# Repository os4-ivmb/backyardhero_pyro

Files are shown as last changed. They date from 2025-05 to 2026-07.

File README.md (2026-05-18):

# Backyard Hero

An open-source 2.4 GHz wireless fireworks firing system. Custom hardware, a
web-based show builder, sub-10 ms cross-receiver sync — schematics, firmware,
and the host app all public.

<div align="center">
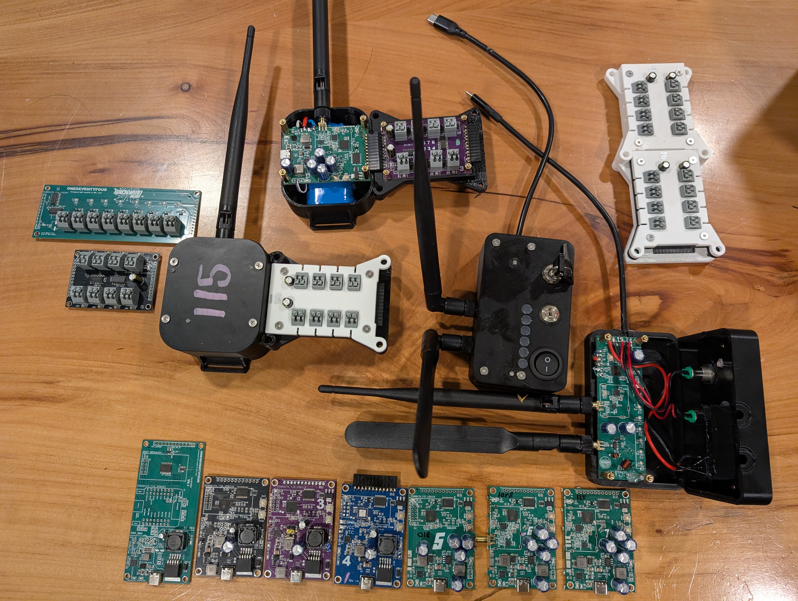
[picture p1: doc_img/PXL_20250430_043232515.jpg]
Backyard Hero — receivers, dongle, and cue modules
  
</div>

## Docs live elsewhere

This README is intentionally short. There are two places to look:

- **[backyard-hero.com](https://backyard-hero.com)** — overview, hardware
  walkthrough, what the system can do, how it gets run, photos. Start here if
  you've just landed on the repo.
- **[Project wiki](https://github.com/os4-ivmb/backyardhero_pyro/wiki)** —
  getting started by OS, system architecture, wire protocol, firmware
  deep-dives, REST API reference, and everything else you need to actually
  build, flash, and run the system.

A few jumping-off points in the wiki:

- [Getting Started](https://github.com/os4-ivmb/backyardhero_pyro/wiki/Getting-Started)
  ([macOS](https://github.com/os4-ivmb/backyardhero_pyro/wiki/Getting-Started-macOS)
  · [Linux](https://github.com/os4-ivmb/backyardhero_pyro/wiki/Getting-Started-Linux)
  · [Windows](https://github.com/os4-ivmb/backyardhero_pyro/wiki/Getting-Started-Windows))
- [System Architecture](https://github.com/os4-ivmb/backyardhero_pyro/wiki/System-Architecture)
  and [Glossary & Terms](https://github.com/os4-ivmb/backyardhero_pyro/wiki/Glossary-and-Terms)
- [Connecting the Dongle](https://github.com/os4-ivmb/backyardhero_pyro/wiki/Connecting-the-Dongle)
  · [Flashing a Receiver](https://github.com/os4-ivmb/backyardhero_pyro/wiki/Flashing-a-Receiver)

## Running it locally

Each platform has its own folder under `host/run/`. Pick yours, follow the
README inside.

| Platform | Folder | Quickstart |
| --- | --- | --- |
| **Raspberry Pi** (controller / AP) | [`host/run/pi/`](host/run/pi/README.md) | `sudo host/run/pi/install.sh` |
| **macOS** (dev) | [`host/run/osx/`](host/run/osx/README.md) | `host/run/osx/start.sh` (prod) or `start-dev.sh` (hot reload) |
| **Windows** (dev) | [`host/run/windows/`](host/run/windows/README.md) | `host\run\windows\start.bat` |

Then open `http://localhost:1776` (or `http://backyardhero/` on the Pi's AP).

## Repository layout

- `host/` — Next.js show builder, Python firework daemon, WebSocket server,
  serial bridge.
- `devices/` — receiver, dongle, and cue-module firmware, plus PCB design
  notes and enclosure CAD.

## License

[DBAD](https://dbad-license.org/) — don't be a dick.

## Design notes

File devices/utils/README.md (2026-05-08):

# devices/utils

Host-side helpers for building and provisioning OS4 firmware.

## Receiver flow (FW v14+)

Pre-v14 each receiver needed its own custom build because `NODE_ID` and
`RECEIVER_IDENT` were `#define`s in the sketch. v14 moves identity into
the chip's NVS partition (`byh_rx` namespace) so one binary serves the
whole fleet, and identity is written over USB serial after flashing.

The flash workflow is built around **NVS preservation**: routine firmware
updates write only the app partition, so once a receiver has been
provisioned, its `NODE_ID` and ident persist forever -- through every
firmware update, until you explicitly wipe them.

### One-time setup (host)

```bash
brew install arduino-cli
```

That's it. `arduino-cli` reuses your existing `~/Library/Arduino15`
install for the ESP32 core, so you don't have to reinstall anything if
you've ever built via the Arduino IDE on this machine.

`flash_receiver.py` self-bootstraps a Python venv at `devices/utils/.venv`
on first run and installs `pyserial` + `esptool` into it -- you don't
need to deal with Homebrew Python's PEP 668 protection or manage
dependencies by hand. To rebuild the venv from scratch (e.g. after a
Python upgrade), just `rm -rf devices/utils/.venv` and run the script
again.

### Build

```bash
devices/utils/build_receiver.sh
```

- Reads `#define FW_VERSION` from `devices/os4_receiver/os4_receiver.ino`.
- Compiles for `esp32:esp32:lolin_s2_mini` via `arduino-cli`.
- Writes the same four files the Arduino IDE produces, into
  `devices/os4_receiver/bin/`:
  - `os4_receiver_v<N>.bin` -- app partition (~340 KB). Flashed at
    `0x10000` for routine updates.
  - `os4_receiver_v<N>.bootloader.bin` -- chip bootloader. Flashed at
    `0x1000` during `--full`.
  - `os4_receiver_v<N>.partitions.bin` -- partition table. Flashed at
    `0x8000` during `--full`.
  - `os4_receiver_v<N>.boot_app0.bin` -- OTA next-app pointer (static
    arduino-esp32 file). Flashed at `0xe000` during `--full`.
- Updates `bin/latest.*` symlinks.

To produce new artifacts alongside the old ones, bump `FW_VERSION` in
the sketch (and add notes to the version-history block at the top of the
file). Re-running at the same `FW_VERSION` overwrites the existing bins.

### Flash + provision

Three modes, picked via flags. The script always picks the
highest-versioned matching bin (override with `--bin <path>`).

#### Routine update (already-provisioned receiver)

```bash
devices/utils/flash_receiver.py
```

App-only flash at `0x10000` -- exactly what the Arduino IDE does for an
upload to a board that's already been flashed. Preserves `NODE_ID` and
ident. After the flash, the script reads the boot banner over serial
and confirms the receiver came back up with its previous identity.

#### First-time flash (virgin chip / recovery)

```bash
devices/utils/flash_receiver.py --full
```

Writes bootloader + partitions + boot_app0 + app in one esptool
invocation -- exactly the four-file layout the Arduino IDE writes for a
fresh upload. **Also preserves NVS**, because the default ESP32-S2
partition table puts NVS at `0x9000-0xdfff`, in the gap between the
partition table (`0x8000-0x8fff`) and `boot_app0` (`0xe000-0xffff`),
and we don't write anything in that gap.

After the flash, prompts for receiver number 1-254 and sends `SETID
<node_id> RX<node_id>` over serial to provision the new identity. (For
a brand-new chip, NVS is empty after this flash and the receiver boots
into UNPROVISIONED mode -- which is exactly what `SETID` resolves.)

Use this for:
- A brand new ESP32-S2 chip that has never been flashed.
- Recovery after a corrupt partition table or other surgery.
- Whenever the partition layout itself changes (e.g. you added or
  resized a partition in `partitions.csv`).

#### Re-provision (change the receiver number on an existing unit)

```bash
devices/utils/flash_receiver.py --set-id
```

App-only flash followed by an interactive `SETID`. Use this to renumber
a receiver in the field (or to provision one that ended up
unprovisioned for any reason) without wiping the rest of NVS.

Equivalent to `flash_receiver.py` followed by manually sending a
`SETID` command -- but in one step.

#### Skip the prompts

```bash
devices/utils/flash_receiver.py --full --port /dev/tty.usbmodem01 --node 146
# (ident defaults to RX146; pass --ident to override)
```

`--node` and `--ident` work with both `--full` and `--set-id`.

### Re-provisioning a unit in the field (no flash)

You don't need to re-flash to change `NODE_ID`. Use the dedicated
helper:

```bash
devices/utils/set_node_id.py                            # prompts for everything
devices/utils/set_node_id.py --node 146                 # ident defaults to RX146
devices/utils/set_node_id.py --get                      # just read current ID
devices/utils/set_node_id.py --wipe                     # back to UNPROVISIONED
```

This is the right tool when the chip already has working firmware and
you just need to renumber it. (`flash_receiver.py --set-id` does the
same thing but also re-flashes the app first.)

Under the hood, both scripts open the receiver's USB serial port at
115200 8N1 and send one of these commands -- which the firmware accepts
at any time:

```
GETID
SETID <node_id> <ident>
WIPEID
```

`SETID` and `WIPEID` reboot the chip after writing.

### Behavior summary

| Mode | Files written | NVS  | Auto SETID | When to use |
| --- | --- | ---- | --- | --- |
| (default)  | app @ 0x10000 | kept | no | routine updates |
| `--full` | bootloader + partitions + boot_app0 + app | kept | yes (prompt) | virgin chip / recovery |
| `--set-id` | app @ 0x10000 | kept | yes (prompt)  | renumber a unit |

### Troubleshooting

**`Could not configure port: (6, 'Device not configured')` or
`Connecting...` hangs at the "connecting" step.**

The lolin_s2_mini runs its user firmware over USB-CDC, and the chip's
ability to respond to esptool's auto-reset signals (DTR/RTS over USB)
depends on what the user app is doing at the moment esptool tries to
talk. When auto-reset fails, the script automatically prompts you to
put the chip into ROM bootloader mode by hand:

1. Press and HOLD the BOOT button on the receiver.
2. While still holding BOOT, press and release RESET.
3. Release BOOT.
4. Press Enter at the prompt.

The script then retries with `--before no_reset` and the flash
proceeds. Once the new firmware boots, auto-reset usually works again
for the next flash.

If the retry also fails:
- Unplug and replug the receiver to recycle the USB endpoint.
- Make sure nothing else is holding the serial port (Arduino IDE Serial
  Monitor, `screen`, another terminal, etc.).
- Try a different USB cable -- some "charging" cables don't carry data.

**`esptool not found` or `pyserial not installed`.**

`flash_receiver.py` self-bootstraps a venv at `devices/utils/.venv` on
first run. If something is wrong with the venv, just delete it and
re-run:

    rm -rf devices/utils/.venv

### Future: OTA

The same app-only artifact (`os4_receiver_v<N>.bin`) is what an OTA
flow will push -- both paths land at offset `0x10000` and preserve NVS,
so a unit can be provisioned once over USB and updated indefinitely
over the air.

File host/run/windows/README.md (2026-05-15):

# host/run/windows -- Windows development

Local development on Windows with Docker Desktop and the ESP32-S2
dongle plugged into USB (typically `COM3` / `COM4`).

## Files in this folder

| File | What it does |
| --- | --- |
| `start.bat` | Prod launcher: pulls `os4ivmb/backyardhero:latest`, starts the bridge + Docker stack. |
| `docker-compose.yml` | Prod compose. Maps host port 1776 (not 80 -- avoids collisions with IIS or other Windows services). |
| `build_and_push_docker.bat` | Multi-arch build + push to Docker Hub (mirror of the osx script). |

There's no `start-dev.bat` yet -- if you need hot-reload dev on
Windows, run WSL2 and use the `osx/` flow from there (Linux paths
work the same as the mac scripts and Docker Desktop integrates with
WSL2).

## Prereqs

- Windows 10/11 with Docker Desktop installed and running.
- Python 3 in `PATH`. Install from <https://python.org>; check
  "Add Python to PATH" during install.
- The dongle plugged into USB. It'll show up as `COM<N>` in Device
  Manager.

## Run it

```cmd
cd host\run\windows
start.bat
```

The script opens a separate window for the TCP-to-serial bridge
(close it to stop the bridge) and runs `docker compose up` in the
main window (Ctrl-C to stop the stack).

Open <http://localhost:1776/> in your browser.

## Why no port 80?

Same reason as macOS: Windows dev boxes often have IIS, other
services, or just-in-case dev servers on port 80. Binding it from
Docker risks "port already in use" errors. The Pi compose binds 80
because the Pi is dedicated hardware; on a Windows dev box you're
just hitting localhost so :1776 is fine.

## Cutting a new image for the Pi

```cmd
cd host\run\windows
build_and_push_docker.bat
build_and_push_docker.bat --no-push
```

You'll need `docker login` first. The script pulls `host_version`
from `host\config\systemcfg.json` via PowerShell.

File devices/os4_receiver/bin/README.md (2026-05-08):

# Receiver firmware binaries

Build artifacts produced by `devices/utils/build_receiver.sh` land here.

Per `FW_VERSION` we keep four files, exactly the ones the Arduino IDE
flashes when it pushes a build:

- `os4_receiver_v<N>.bin` -- app partition (~340 KB). Flashed at
  **0x10000**. This is the only file `flash_receiver.py` writes for a
  routine update.
- `os4_receiver_v<N>.bootloader.bin` -- chip bootloader. Flashed at
  **0x1000** during a `--full` first-time flash.
- `os4_receiver_v<N>.partitions.bin` -- partition table. Flashed at
  **0x8000** during a `--full` first-time flash.
- `os4_receiver_v<N>.boot_app0.bin` -- OTA "next-app" pointer (static
  arduino-esp32 file, copied here so the flash helper doesn't have to
  dig through `~/Library/Arduino15`). Flashed at **0xe000** during a
  `--full` first-time flash.

NVS lives at `0x9000-0xdfff` in the default ESP32-S2 partition table --
in the gap between the partition table and `boot_app0`. `flash_receiver.py`
never writes anything in that gap, so **NODE_ID and RECEIVER_IDENT
survive both routine flashes and `--full` flashes**.

Symlinks:

- `latest.bin` -> newest `os4_receiver_v<N>.bin`
- `latest.bootloader.bin` -> newest `os4_receiver_v<N>.bootloader.bin`
- `latest.partitions.bin` -> newest `os4_receiver_v<N>.partitions.bin`
- `latest.boot_app0.bin` -> newest `os4_receiver_v<N>.boot_app0.bin`

`FW_VERSION` is read from `#define FW_VERSION` in `os4_receiver.ino` at
build time. Re-building at the same `FW_VERSION` overwrites all four
files; bump `FW_VERSION` in the sketch to keep multiple versions
side-by-side.

`.bin` files are gitignored -- these are local build artifacts. Tag
releases in git if you want to pin a particular firmware version.

See `devices/utils/README.md` for the flash workflow.

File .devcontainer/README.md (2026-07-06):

# .devcontainer — Backyard Hero host

A [Dev Container](https://containers.dev) that runs the full host stack
(Next.js show builder + Python firework daemon + WebSocket server) with
hot reload. It reuses the same image and dev config as
`host/run/osx/docker-compose-dev.yml`.

## Prereqs

- Docker (Docker Desktop with **WSL integration enabled** for this distro,
  or a native Docker Engine reachable from this shell).
- VS Code with the **Dev Containers** extension, or the
  [`devcontainer` CLI](https://github.com/devcontainers/cli).

> Check Docker is reachable first: `docker info` should succeed. If you're on
> WSL2 and it says "daemon not reachable", turn on
> *Docker Desktop → Settings → Resources → WSL Integration* for this distro.

## Open it

**VS Code:** open the repo, then *Dev Containers: Reopen in Container*
(Command Palette). First build runs `npm ci` + `next build` inside the
image — a few minutes; later starts are ~10s.

**CLI:**

```bash
devcontainer up --workspace-folder .
```

When it's up, the app is on <http://localhost:1776> and the WebSocket
server on `8090` (both auto-forwarded).

## What runs where

| Process | How | Restart after edits |
| --- | --- | --- |
| Next.js app (`byh_app`) | `npm run dev` under supervisord | HMR, automatic (~1s) |
| Python daemon (`pc_daemon`) | supervisord `firework-daemon` | `supervisorctl restart firework-daemon` |
| WebSocket server (`ws_server`) | supervisord `websock` | `supervisorctl restart websock` |

Run the `supervisorctl` commands from a terminal **inside** the container
(the VS Code integrated terminal), or from the host via Compose:

```bash
docker compose -f .devcontainer/docker-compose.yml exec firework-system \
  supervisorctl restart firework-daemon
```

Both Python services have `autorestart=true`, so if `supervisorctl` can't
reach the socket you can also just `pkill -f pc_daemon.py` and supervisor
respawns it.

> The container has no fixed name (see the compose file for why), so address
> it by the **service** name `firework-system`, not a container name.

## Editing source

The whole repo is mounted at `/workspaces/backyardhero_pyro` and the
workspace opens there (the repo root), so the `.git` dir and everything
else are visible and VS Code's Git integration works. `git` itself is
installed via the `ghcr.io/devcontainers/features/git` feature (the
`node:22-slim` base image doesn't ship it), and the repo is marked a
`safe.directory` on create. The app source
(`host/byh_app/backyardhero`) and `host/pythings` are *also* bind-mounted
into `/app`, so edits there hot-reload regardless of which path you open.

`node_modules` and `.next` live in **named volumes** (`byh_node_modules`,
`byh_next`) so the container keeps its Linux-built binaries instead of
inheriting host-built ones (which crash with "invalid ELF header"). Reset
them if deps get weird:

```bash
docker compose -f .devcontainer/docker-compose.yml down --volumes
```

## Hardware / the dongle

There's no USB dongle inside the container.

**By default the container fires nothing.** `supervisord.devcontainer.conf`
runs an in-container **mock bridge** (`host/pythings/mock_bridge/`) and points
the daemon at it (`BYH_BRIDGE_HOST=127.0.0.1`). The mock reports a healthy
dongle and **silently swallows every fire command** — the UI shows CONNECTED
and firing "succeeds" on the wire, but nothing physically fires. This is what
lets the builder/UI and everything non-hardware work with no dongle attached.

### Using real hardware from the dev container

Because the daemon is wired to the mock by default, you must explicitly take
the mock out of the loop and re-point the daemon at the **host-side TCP↔serial
bridge** (`host/tcp_serial_bridge/`, run on the host with `SERIAL_PORT` set to
your dongle's port):

1. Start the host-side bridge on the host (not in the container).
2. Stop the mock so it isn't holding the port / answering as a fake dongle:
   `supervisorctl stop mock-bridge`.
3. Re-point the daemon at the host bridge instead of `127.0.0.1`: set
   `BYH_BRIDGE_HOST=host.docker.internal` (and `BYH_BRIDGE_PORT` if you changed
   it) for `firework-daemon`, then `supervisorctl restart firework-daemon`.

Until you do all three, "CONNECTED" and successful fires in the UI are the
**mock** — no receiver will actually fire.

## Rebuild triggers

`Dockerfile`, `supervisord*.conf`, or `package.json` dep changes need a
rebuild: *Dev Containers: Rebuild Container* (or
`devcontainer up --build`). Source and Python edits do not.

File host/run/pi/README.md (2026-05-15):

# host/run/pi -- Raspberry Pi deployment

Turnkey install + run for a Raspberry Pi acting as the firework
controller. Tested on Pi 5 (Bookworm 64-bit) but works on most modern
Pis and on generic Ubuntu/Debian with minor variations.

## Files in this folder

| File | What it does |
| --- | --- |
| `install.sh` | One-shot bare-OS installer. Installs Docker, hostapd, dnsmasq, udev rules, the dongle stable symlink, the `byh-host` systemd unit, WiFi AP, NAT for AP clients. |
| `update.sh` | One-button update: `git pull` + `docker compose pull` + re-run `install.sh` + restart `byh-host`. The day-to-day "bring me up to latest". |
| `start.sh` | Prod launcher (invoked by the systemd unit). Brings up the host-side TCP-to-serial bridge + the Docker stack via `docker-compose.yml`. |
| `start-dev.sh` | Dev launcher. Same as `start.sh` but builds the image locally and bind-mounts source for hot reload. |
| `docker-compose.yml` | Prod compose: pulls `os4ivmb/backyardhero:latest`, binds host ports 80+1776+8090, wires `host.docker.internal` for the bridge, tolerant of being offline. |
| `docker-compose-dev.yml` | Dev compose: builds locally, bind-mounts source. Same port + extra_hosts behavior as prod. |
| `update_dongle.sh` | One-button "pull latest -> build -> flash" for the ESP32-S2 dongle plugged into the Pi. |

## First-time install

On a fresh Pi OS (or Ubuntu) install:

```bash
# Clone somewhere convenient (the installer defaults to /opt/backyardhero
# if you don't pass --repo-dir):
sudo apt update && sudo apt install -y git
git clone https://github.com/os4-ivmb/backyardhero_pyro.git ~/backyardhero
sudo ~/backyardhero/host/run/pi/install.sh
```

The installer:
1. Installs apt deps (Docker, hostapd, dnsmasq, etc.).
2. Adds your user to `docker` and `dialout` groups.
3. Sets up the `/dev/byh_dongle` udev rule so the dongle has a
   stable name regardless of what `/dev/ttyACM*` slot it lands on.
4. Pre-pulls the Backyard Hero Docker image.
5. Installs `byh-host.service` (this file's `start.sh` is the ExecStart).
6. Configures the Pi's WiFi as an AP (`hostapd` + `dnsmasq` + NAT so
   AP clients can reach the internet via the Pi's Ethernet uplink).
7. Hands `/opt/backyardhero` over to your user so you can `git pull`
   / rsync changes in without sudo.

Reboot once when it's done so udev + group memberships take effect.

Once up, the UI is at:

- `http://backyardhero/` (from any client on the Pi's WiFi AP -- mDNS)
- `http://<pi-ip>/`
- `http://<pi-ip>:1776/` (historical port)

## Routine ops

```bash
sudo systemctl status byh-host         # is it running?
sudo systemctl restart byh-host        # restart after config changes
sudo journalctl -u byh-host -f         # tail the stack logs
sudo journalctl -u hostapd -u dnsmasq -f   # tail the AP logs

# Update everything (source + image + system state + restart):
sudo /opt/backyardhero/host/run/pi/update.sh

# Pull a newer image only (skip git + install steps):
sudo /opt/backyardhero/host/run/pi/update.sh --no-source --no-install

# Flash the dongle from this Pi (pull latest firmware -> build -> flash):
sudo /opt/backyardhero/host/run/pi/update_dongle.sh
```

## Iterating on the Pi (dev mode)

When you want to iterate on source code that's been rsync'd over from
a dev box:

```bash
sudo systemctl stop byh-host         # free up ports 80/1776/8090 and the dongle
cd /opt/backyardhero/host/run/pi
./start-dev.sh                       # build + start dev stack in foreground
```

While `start-dev.sh` is running, source changes hot-reload:

- **Frontend / Next.js API routes** -- HMR picks them up automatically
  (~1s after save).
- **Python daemon** --
  `docker exec firework-system supervisorctl restart firework-daemon`
- **WebSocket server** --
  `docker exec firework-system supervisorctl restart websock`
- **Bridge changes** -- Ctrl-C `start-dev.sh` and re-run it.
- **Dockerfile / supervisord changes** -- Ctrl-C and re-run (it rebuilds
  changed layers).

When done iterating, Ctrl-C, then bring prod back:

```bash
sudo systemctl start byh-host
```

First time `start-dev.sh` runs on a Pi the build takes 10-15 min
(`npm ci` dominates); subsequent runs are ~30s thanks to Docker layer
caching.

## Uninstall

```bash
sudo /opt/backyardhero/host/run/pi/install.sh --uninstall
```

Removes the systemd units, the udev rule, the AP setup, NAT rules, and
the dnsmasq/hostapd configs. Leaves the repo and the Docker image
behind for you to clean up manually if you want.

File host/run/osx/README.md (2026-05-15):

# host/run/osx -- macOS development

Local development on a mac with Docker Desktop and the ESP32-S2 dongle
plugged into USB.

## Files in this folder

| File | What it does |
| --- | --- |
| `start.sh` | Prod launcher: pulls `os4ivmb/backyardhero:latest`, starts the bridge + Docker stack. |
| `start-dev.sh` | Dev launcher: builds locally from `host/Dockerfile`, bind-mounts source for hot reload. |
| `docker-compose.yml` | Prod compose. Maps host port 1776 (not 80 -- mac dev boxes often have other things on 80). |
| `docker-compose-dev.yml` | Dev compose. Same port layout, source bind-mounted, builds from `host/Dockerfile`. |
| `build_and_push_docker.sh` | Multi-arch (`linux/amd64,linux/arm64`) build + push to Docker Hub. This is how the prebuilt image the Pi consumes gets cut. |

## Prereqs

- macOS with Docker Desktop running.
- Python 3 (system Python is fine -- the launcher creates its own venv
  under `host/tcp_serial_bridge/venv` on first run).
- The dongle plugged into USB. It'll show up as `/dev/tty.usbmodem*`.

## Run it

```bash
# Production: pulls latest image, runs against it.
cd host/run/osx
./start.sh

# Development: builds locally, hot-reloads source.
./start-dev.sh
```

Open <http://localhost:1776/> when it's up.

Ctrl-C in the launcher terminal stops both the bridge and the Docker
stack.

## Refresh loop in dev

While `start-dev.sh` is running:

- **Frontend / Next.js API routes** -- HMR picks up edits in ~1s.
- **Python daemon** --
  `docker exec firework-system supervisorctl restart firework-daemon`
- **WebSocket server** --
  `docker exec firework-system supervisorctl restart websock`
- **Bridge (`host/tcp_serial_bridge/`)** -- Ctrl-C the launcher and
  re-run.
- **Dockerfile / supervisord / package.json deps** -- Ctrl-C and
  re-run; `docker compose up --build` will rebuild changed layers.

## Cutting a new image for the Pi

`build_and_push_docker.sh` is the source of truth for what goes onto
the Pi:

```bash
cd host/run/osx
./build_and_push_docker.sh                  # multi-arch, :latest + :v<host_version>
./build_and_push_docker.sh --no-push        # local build only
./build_and_push_docker.sh --tag rc1        # extra :rc1 tag
```

The version comes from `host_version` in `host/config/systemcfg.json`.
You'll need to `docker login` first for the push step. The Pi pulls
`os4ivmb/backyardhero:latest` by default.

## Why no port 80?

Docker Desktop will happily bind host port 80, but doing so on a dev
mac risks colliding with anything else listening there (apache, nginx,
a local dev server you forgot about, etc.). The Pi compose binds 80
because the Pi is a dedicated device and the friendly URL
(`http://backyardhero/`) only matters when a phone is connecting via
the AP. On a mac you're just hitting localhost, so :1776 is fine.

## Why no `extra_hosts`?

Docker Desktop on macOS resolves `host.docker.internal` automatically.
The Pi compose has to wire it up explicitly because Docker Engine on
Linux doesn't. Both compose files do the right thing for their
target without conditionals.

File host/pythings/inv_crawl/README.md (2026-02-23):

# Inventory Catalog Crawler

This script fetches all fireworks data from the BYH catalog and saves it to `/data/catalog.json`.

## Usage

```bash
python3 crawl_catalog.py
```

## Output

- **Catalog file**: `/data/catalog.json`
- **Progress file**: `/data/catalog_crawl_progress.json` (updated during crawl)

## Progress File Format

```json
{
  "status": "running|completed|error",
  "current": 5,
  "total": 50,
  "message": "Completed page 5/50...",
  "timestamp": 1234567890
}
```

## Requirements

No additional requirements beyond Python standard library.

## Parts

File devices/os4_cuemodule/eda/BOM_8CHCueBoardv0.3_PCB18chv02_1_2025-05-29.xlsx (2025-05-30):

No. | Quantity | Comment | Designator | Footprint | Value | Manufacturer Part | Manufacturer | Supplier Part | Supplier
1 | 8 | 100nF | C1,C2,C3,C4,C5,C6,C7,C8 | C0402 | 100nF | CL05B104KO5NNNC | SAMSUNG(三星) | C1525 | LCSC
2 | 2 | 100nF | C9,C10 | C0603 | 100nF | CC0603KRX7R9BB104 | YAGEO(国巨) | C14663 | LCSC
3 | 2 | 470uF | C11,C12 | CAP-TH_BD6.3-P2.50-D1.0-FD | 470uF | GR477M010E12RR0VH4FP0 | CX(承兴) | C43332 | LCSC
4 | 8 | WJ250B-3.5-2P | CN1,CN2,CN3,CN4,CN5,CN6,CN7,CN8 | CONN-TH_WJ250B-3.50-2P |  | WJ250B-3.5-2P | KANGNEX(康奈克斯电气) | C8454 | LCSC
5 | 1 | SN74HC165DR | CONT_REG | SOP-16_L10.0-W3.9-P1.27-LS6.0-BL |  | SN74HC165DR | TI(德州仪器) | C61060 | LCSC
6 | 1 | PM254-1-12-W-8.5 | IN_HEADER | HDR-TH_12P-P2.54-H-F-W10.0-N |  | PM254-1-12-W-8.5 | HCTL(华灿天禄) | C2897394 | LCSC
7 | 8 | XL-1615RGBC-WS2812B | LED1,LED2,LED3,LED4,LED5,LED6,LED7,LED8 | LED-SMD_4P-L1.6-W1.5_XL-1615RGBC-WS2812B |  | XL-1615RGBC-WS2812B | XINGLIGHT(成兴光) | C5349954 | LCSC
8 | 1 | A2541WR-12P | OUT_HEADER | HDR-TH_12P-P2.54-V-M |  | A2541WR-12P | CJT(长江连接器) | C225498 | LCSC
9 | 1 | 74HC595 | OUT_REG | SOP-16_L9.9-W3.9-P1.27-LS6.0-BL |  | 74HC595 | GR(国睿) | C18164493 | LCSC
10 | 8 | AO3400A | Q1,Q2,Q3,Q4,Q5,Q6,Q7,Q8 | SOT-23-3_L2.9-W1.3-P1.90-LS2.4-BR |  | AO3400A | AOS | C20917 | LCSC
11 | 8 | 220Ω | R1,R2,R3,R4,R5,R6,R7,R8 | R0603 | 220Ω | 0603WAF2200T5E | UNI-ROYAL(厚声) | C22962 | LCSC
12 | 8 | 220Ω | R9,R10,R11,R12,R13,R14,R15,R16 | R0402 | 220Ω | 0402WGF2200TCE | UNI-ROYAL(厚声) | C25091 | LCSC
13 | 1 | 680Ω | R17 | R0603 | 680Ω | 0603WAF6800T5E | UNI-ROYAL(厚声) | C23228 | LCSC
14 | 1 | 1kΩ | R18 | R0402 | 1kΩ | 0402WGF1001TCE | UNI-ROYAL(厚声) | C11702 | LCSC
15 | 16 | 10kΩ | RPDI1,RPDI2,RPDI3,RPDI4,RPDI5,RPDI6,RPDI7,RPDI8,RSR1,RSR2,RSR3,RSR4,RSR5,RSR6,RSR7,RSR8 | R0603 | 10kΩ | 0603WAF1002T5E | UNI-ROYAL(厚声) | C25804 | LCSC
16 | 1 | KT-0805G | U5 | LED0805-R-RD |  | KT-0805G | KENTO | C2297 | LCSC

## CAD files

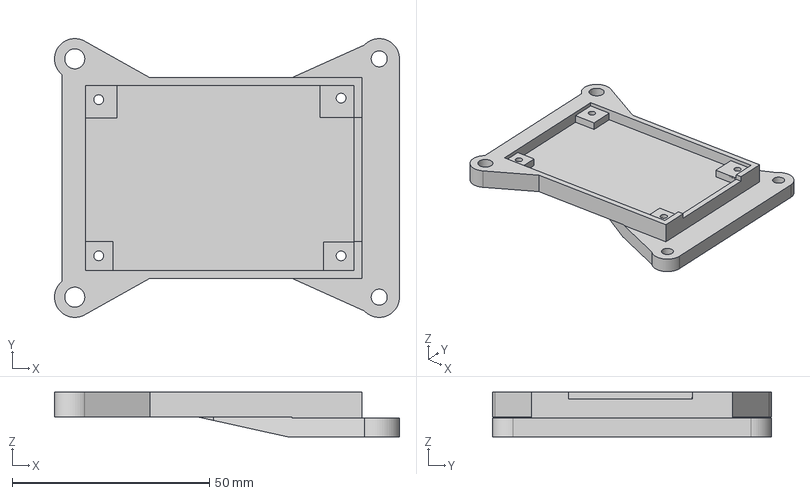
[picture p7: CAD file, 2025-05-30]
devices/os4_cuemodule/case/BYH_8CUE_V03_BOTTOM.step
87.5 x 70.7 x 11.4 mm

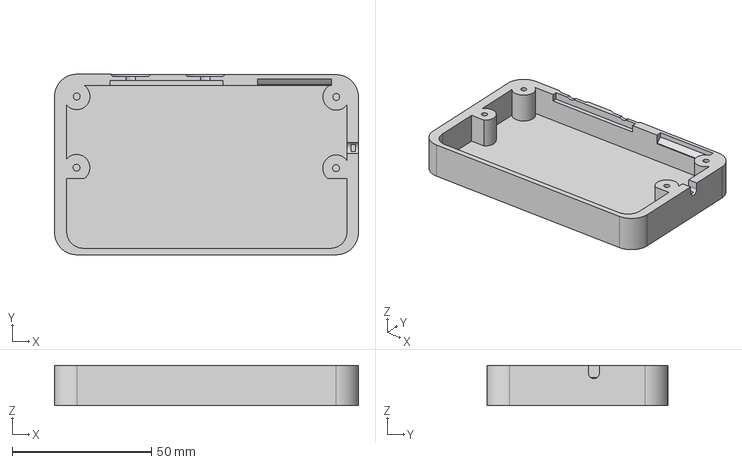
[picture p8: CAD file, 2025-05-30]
devices/os4_dongle/case/BYH_DONGLE_BOTTOM.step
109.3 x 64.9 x 14.5 mm

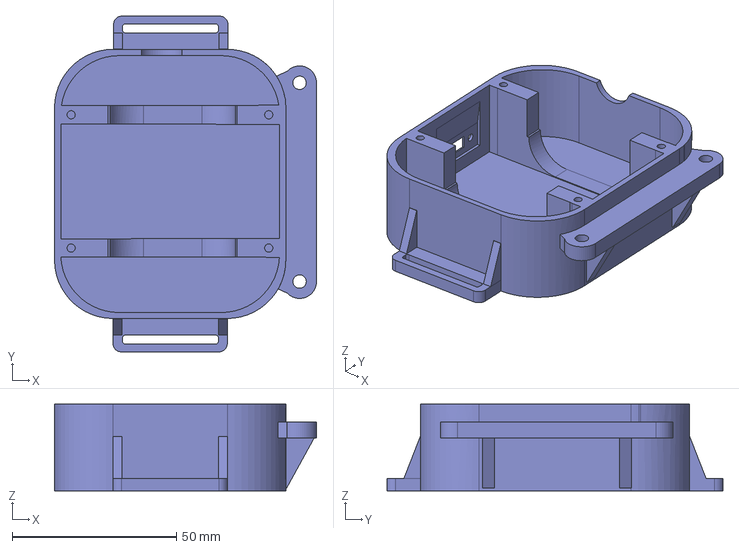
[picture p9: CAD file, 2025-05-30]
devices/os4_receiver/case/BYH_RECEIVER_BOTTOM.step
79.7 x 102.1 x 26.4 mm

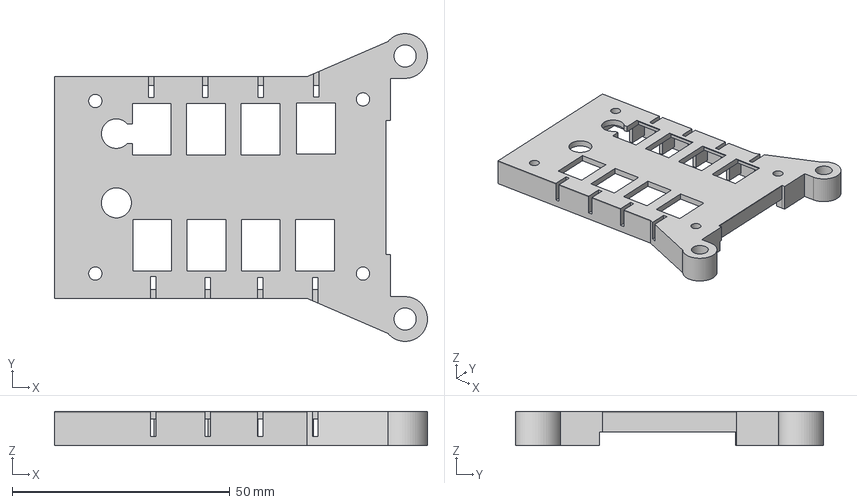
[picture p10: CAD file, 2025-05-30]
devices/os4_cuemodule/case/BYH_8CUE_V03_TOP.step
85.7 x 70.7 x 7.87 mm

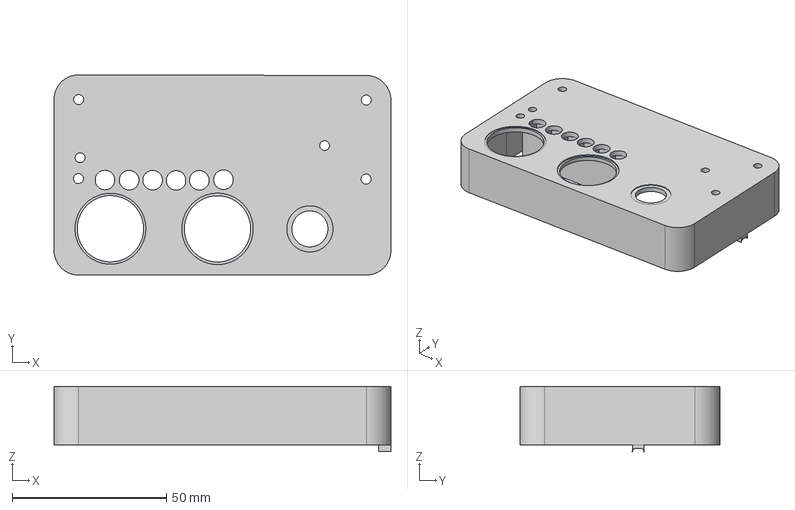
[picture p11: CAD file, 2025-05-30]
devices/os4_dongle/case/BYH_DONGLE_TOP.step
109.3 x 64.9 x 21.2 mm

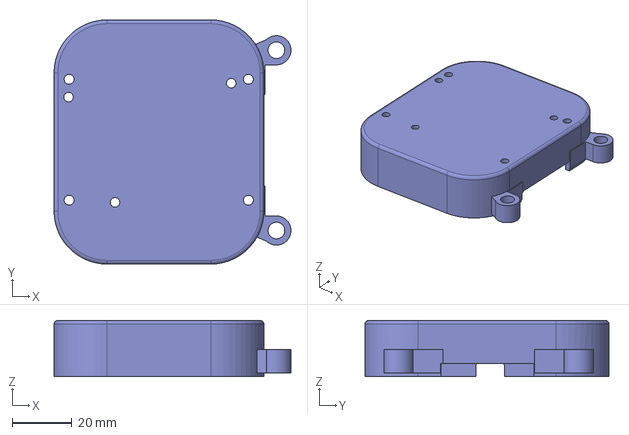
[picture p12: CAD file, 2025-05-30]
devices/os4_receiver/case/BYH_RECEIVER_TOP.step
79.4 x 81.8 x 18.8 mm

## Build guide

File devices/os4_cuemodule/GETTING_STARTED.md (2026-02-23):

# Cue Module Getting Started Guide

> **Note:** This guide covers the OS4 cue module. Each module provides 8 firing channels and can be chained together to support up to 128 cues per receiver.

## Important Safety Cautions

⚠️ **Short Circuit Warning:**
- While the system includes continuity checking, it does **not** detect short circuits
- Ensure your cue wires are **not** twisted together at the terminal and touching

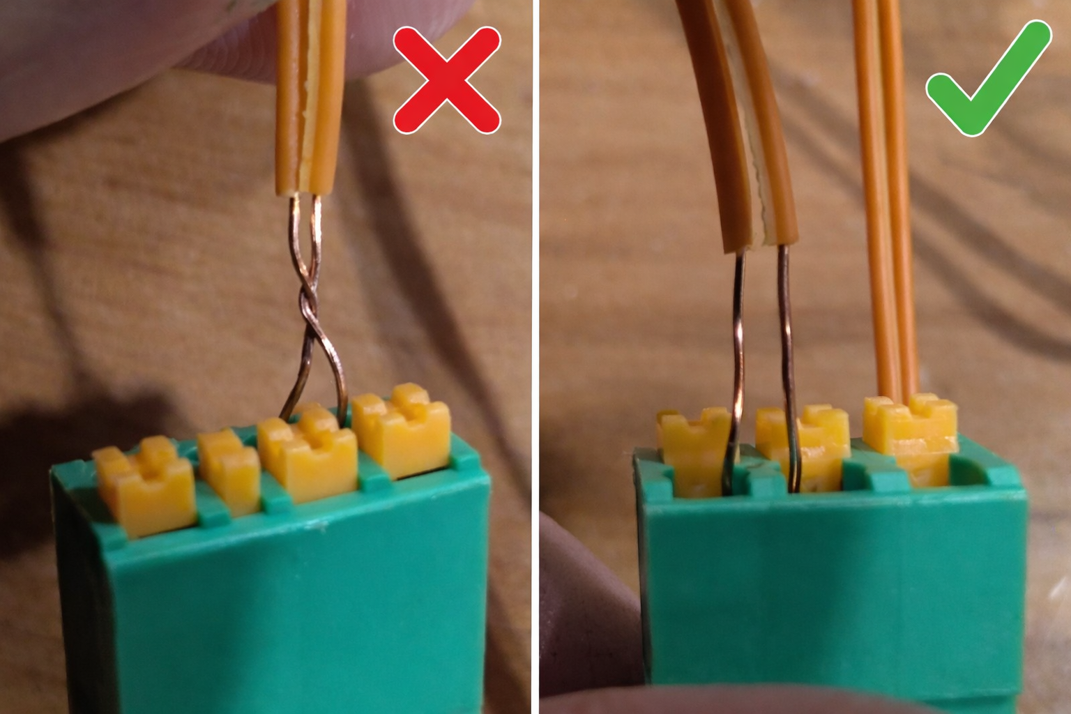
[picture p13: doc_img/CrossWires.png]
Crossed wires example


- If the system fires into a short circuit, it will shut itself down, which will effectively disable that receiver for the rest of the show
- Always verify wire connections before powering on

## Connecting to the Receiver

A cue module should connect snugly to a receiver (or to another cue module in a chain). 

**Connection Tips:**
- If the pins are misaligned, gently rock the cue module up and down to help align them
- **Do not exert excessive force** - this can damage the pins and require re-soldering
- Ensure the connection is secure before powering on 

## Cue Position Numbering

The cue positions run from **close to the receiver**, along the **far side of the antenna**, down the side, then reset to the other side *per module*. The count continues sequentially at the next module in the chain.

**Example: 2 Cue Modules Chained Together**

```
|_____RECEIVER______|
--------CUE----------
1                   5
2                   6
3                   7
4                   8
---------------------
--------CUE----------
9                  13
10                 14
11                 15
12                 16
---------------------
```

**Positioning Pattern:**
- Positions 1-4: Near side (closest to receiver)
- Positions 5-8: Far side (opposite side)
- Next module continues from position 9
- This pattern repeats for each additional module in the chain

## LED Status Indicators

During show execution, the LED lights for each cue will cycle/fade to indicate show state transitions. These states are synchronized with the status lights on the receiver.

### Cue LED States

Each cue position can display one of 5 states:

| Color | State | Description |
|---|---|---|
| **Off** | Standby | No cue assigned in the show, and nothing is plugged in |
| **Blue** | Available | Cue is plugged in, but not assigned in the currently loaded show |
| **Red** | Continuity Required | Cue is assigned in the loaded show, but no ignitor continuity is detected |
| **Green** | Ready | Cue is assigned in the loaded show **and** continuity is detected |
| **Yellow** | Firing | The cue is actively firing |

## Hardware Configuration

The cue module boards come almost complete from the factory. The main configuration decision is how many **bulk capacitors** to add.

### Bulk Capacitors

Bulk capacitors allow cue modules to be chained in much larger lengths and sustain much higher numbers of simultaneously firing cues.

**When to Add Bulk Capacitors:**

- **Not Required:** If you're only using 2-3 chained cue modules maximum, and less than 4 simultaneously firing cues
- **Recommended:** If you're going to 4+ modules or firing 4+ cues simultaneously:
  - Add **1-2 bulk capacitors** to each module, OR
  - Add **3-4 bulk capacitors** to the **end module** in the chain

**Installation:**
Once bulk capacitors are installed (if needed), the modules are ready to use.

## Terminal Types: Push-Style vs Plug-Style

### Push-Style (Legacy)
- **Gray terminals** that require the small gray squares to be pushed down firmly for the port to accept the wire
- **Disadvantage:** Difficult to use in cold weather conditions
- **Status:** Replaced by plug-style in newer versions

### Plug-Style (Current)
- **Recommended:** The newer plug-style terminals have replaced push-style
- **Advantages:**
  - Accepts either **screw-type** or **push-type** male plugs
  - Allows you to easily plug in cues in the field
  - More user-friendly, especially in cold weather
  - Reduces finger strain during setup

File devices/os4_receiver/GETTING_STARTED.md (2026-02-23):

# Receiver Getting Started Guide

> **Note:** This guide covers the OS4 receiver module. For information about other components, see the respective getting started guides.

*(Receiver photo placeholder)*

## With a Completed Module

A completed v9 module is fairly straightforward to use.

### Powering On and Charging

#### Turning On/Off
The board is powered on with the switch beneath the USB port. When powered, a large green square will illuminate near the side furthest from the antenna, indicating the board is active.

#### Charging
The board can be charged with any USB-PD compatible charger. The charging status is indicated by a lit square to the left of the charge port:
- **Red**: Currently charging
- **Green**: Fully charged

### Flashing New Firmware

The receiver can be flashed using either method:

**Method 1: Arduino IDE**
1. Select `LOLIN S2 MINI` as the board type
2. Select the appropriate serial port (the device will appear as a serial device)
3. Upload the firmware

**Method 2: esptool (Direct)**
- Use esptool directly for command-line flashing

**Troubleshooting:**
If the board does not show up as a serial device, force boot flash mode by:
1. Exposing the bare board
2. Hold the BOOT micro button on the board
3. While holding BOOT, press the RESET button
4. Release both buttons - the board should now appear in bootloader mode

### Status Lights
There are 3 status lights located by the output port.

**Startup Sequence:**
On power-up, all 3 LEDs will fade white, then display a battery level indication (red = low, yellow = medium, green = full), followed by a purple fade.

**LED Functions (in order from closest to antenna to farthest):**

**1. Message Indicator (LED #1)**
- **White**: Flashes white for 100ms when a message is received from the dongle, then fades out over 1.5 seconds
- **Off**: No recent messages

**2. Sync/Battery Light (LED #2)**
- **Solid Purple**: Show is currently playing
- **Battery Color Flash**: When not playing, flashes at the end of each 2-second cycle with a color indicating battery level:
  - **Red**: Low battery (~0-33%)
  - **Yellow**: Medium battery (~33-66%)
  - **Green**: High battery (~66-100%)
- Flash duration: 100ms normally, 400ms when show is ready to start
- This allows you to verify receivers are synchronized - all receivers should flash at the same time

**3. Show Run State (LED #3)**
- **Orange**: Loading show (receiving firing instructions)
- **Cyan**: Show loaded, waiting to start
- **Magenta**: Show playing but before start time (waiting for synchronized start)
- **White**: Show is actively running
- **Off**: Standing by (no show loaded)

## Building from a Bare Board

If you're building a receiver from scratch, you'll need the following components:

### Required Components

**Main Board:**
- V9+ receiver board

**RF Components:**
- 2.4GHz antenna
- SMA plug (for antenna connection)

**Power System:**
- 8.4V 18650 battery pack assembly:
  - 2x 18650 batteries
  - 1x 2S battery BMS (Battery Management System)
  - 10k 3950 NTC thermistor (for temperature monitoring)
  - Nickel strip (for battery connections)
  - Heat wrap (for battery pack protection)

**Enclosure:**
- 3D printed housing
- Hardware kit:
  - Screws
  - Standoffs

### Assembly Instructions

> **TODO:** Detailed step-by-step assembly instructions coming soon.

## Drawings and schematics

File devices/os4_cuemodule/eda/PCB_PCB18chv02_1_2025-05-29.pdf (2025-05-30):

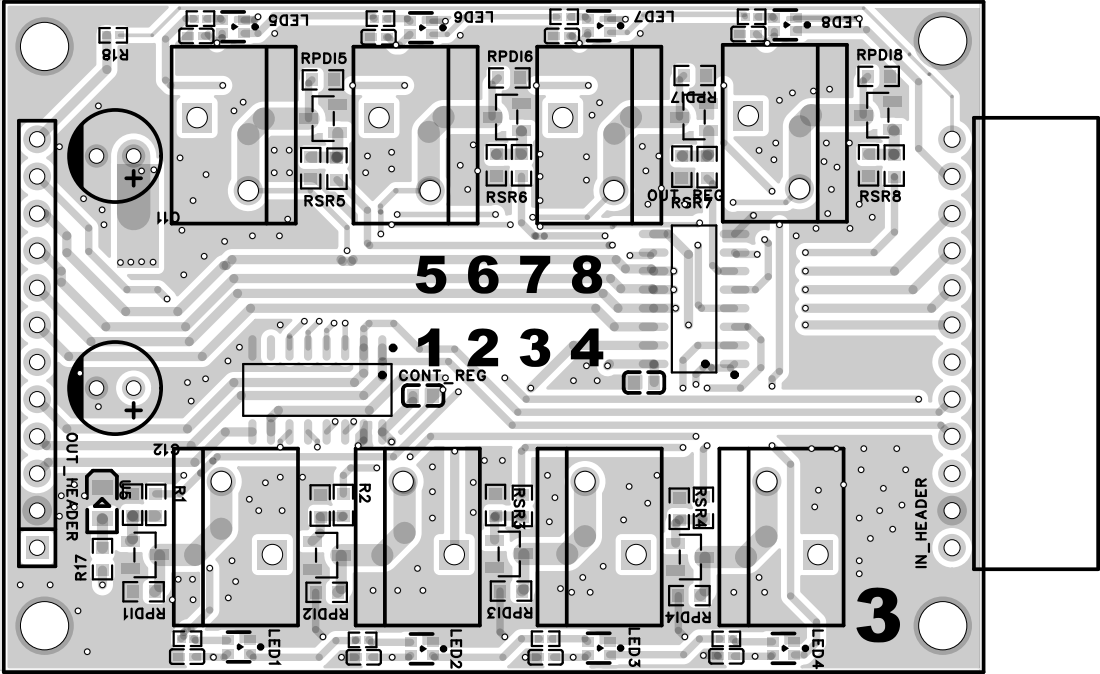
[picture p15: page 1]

# ONESEVENTYFOUR

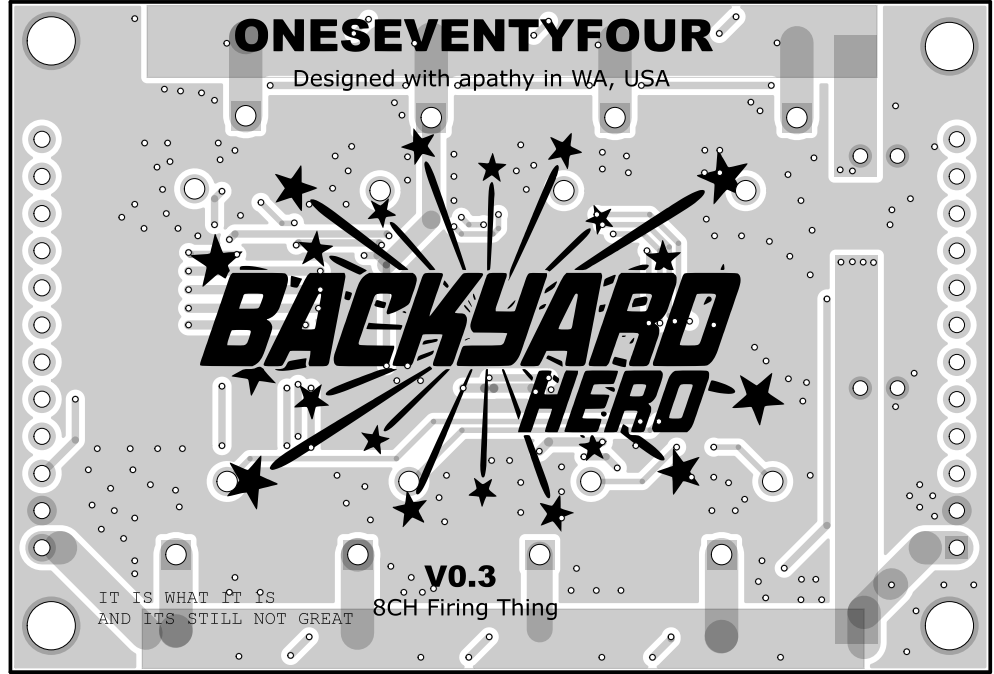
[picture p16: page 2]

Designed with apathy in WA, USA

8CH Firing Thing IT IS WHAT IT IS

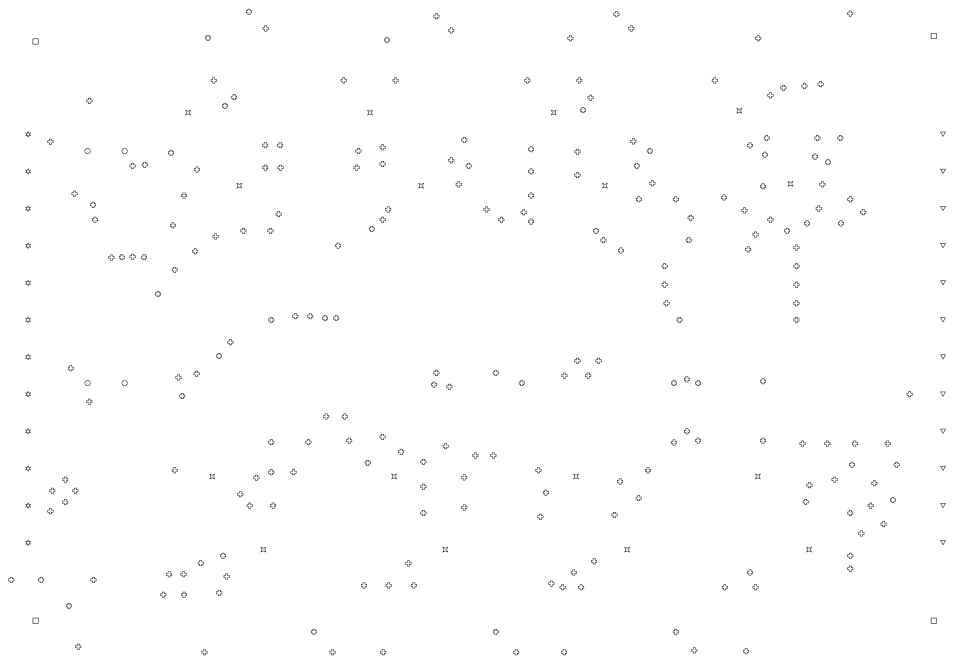
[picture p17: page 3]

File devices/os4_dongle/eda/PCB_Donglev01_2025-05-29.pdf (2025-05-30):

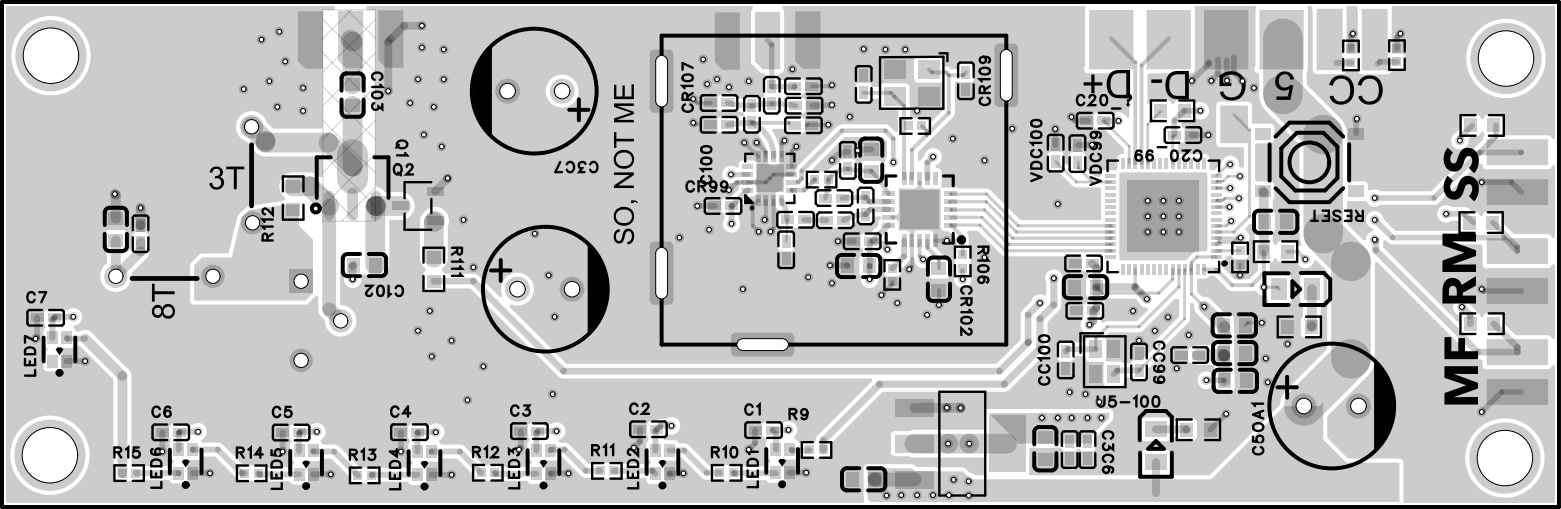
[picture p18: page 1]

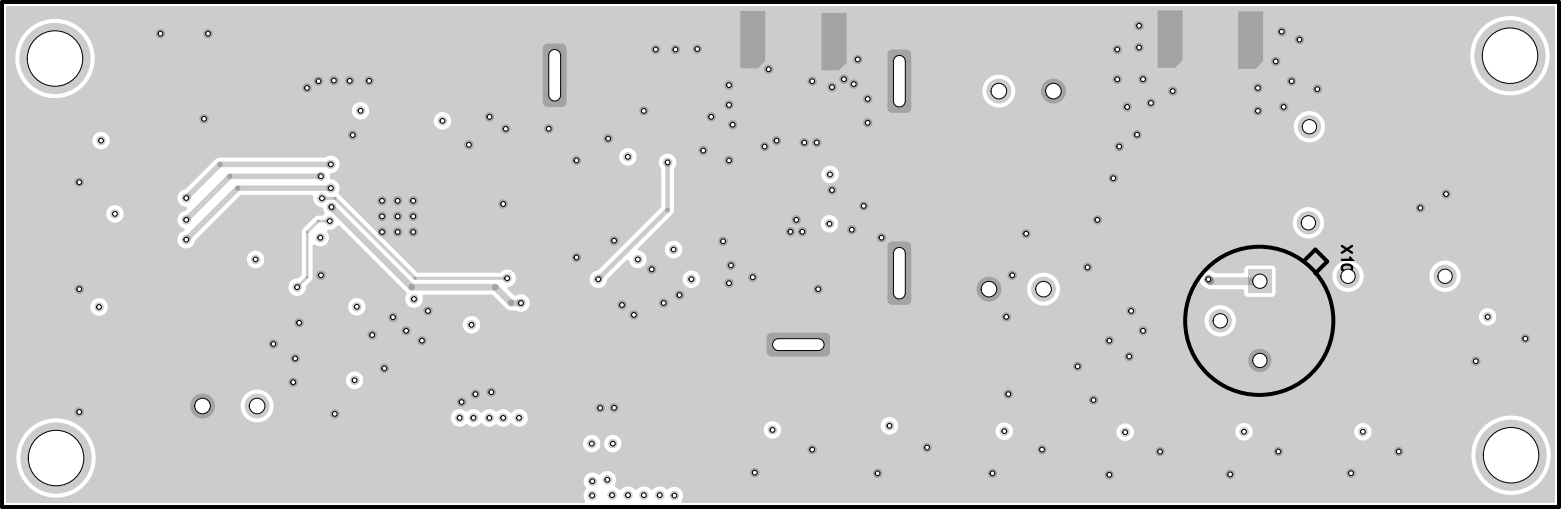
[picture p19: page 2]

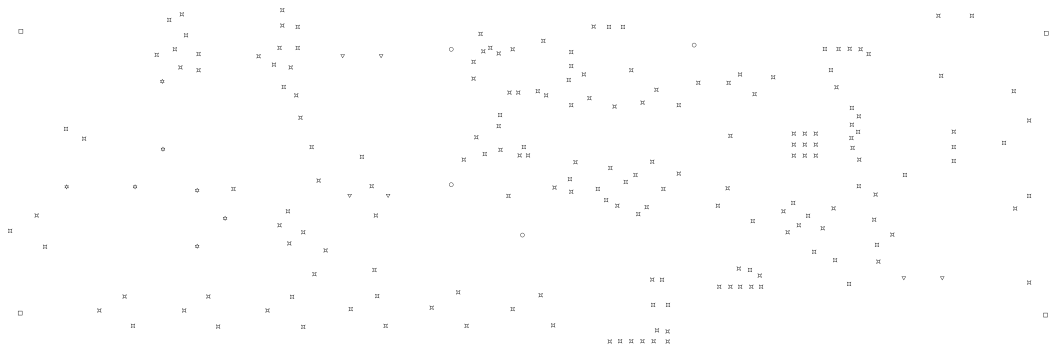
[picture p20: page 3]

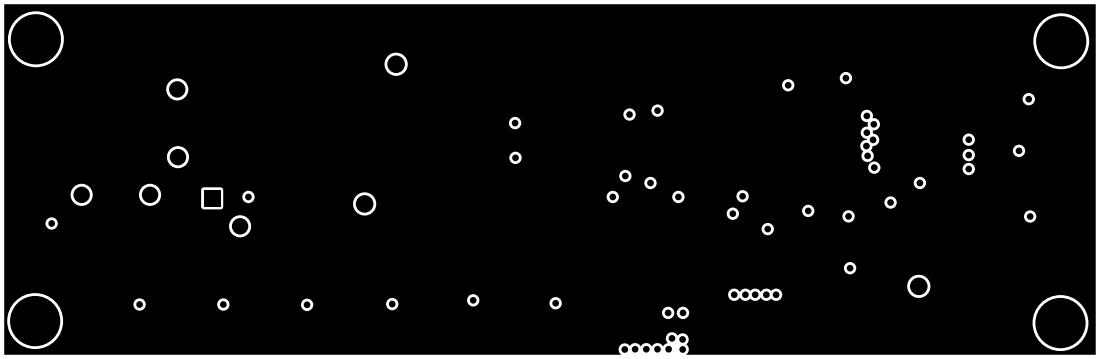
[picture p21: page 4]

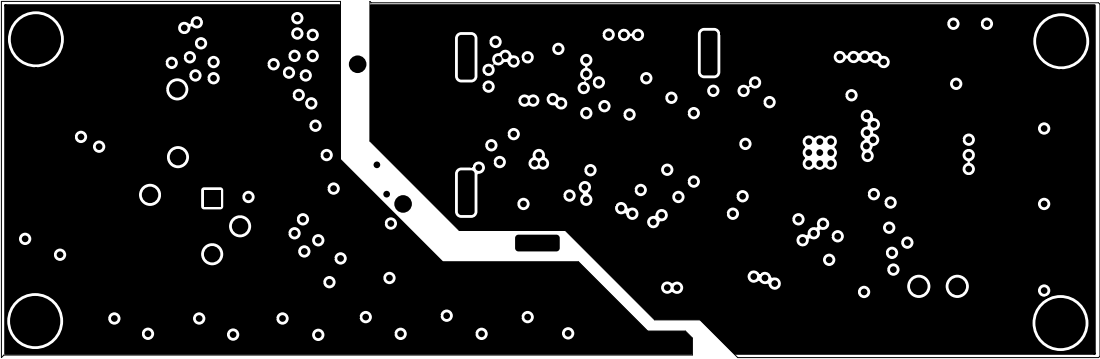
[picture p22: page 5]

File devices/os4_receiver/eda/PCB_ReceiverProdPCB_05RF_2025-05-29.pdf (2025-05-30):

## L801U⁸⁰⁷

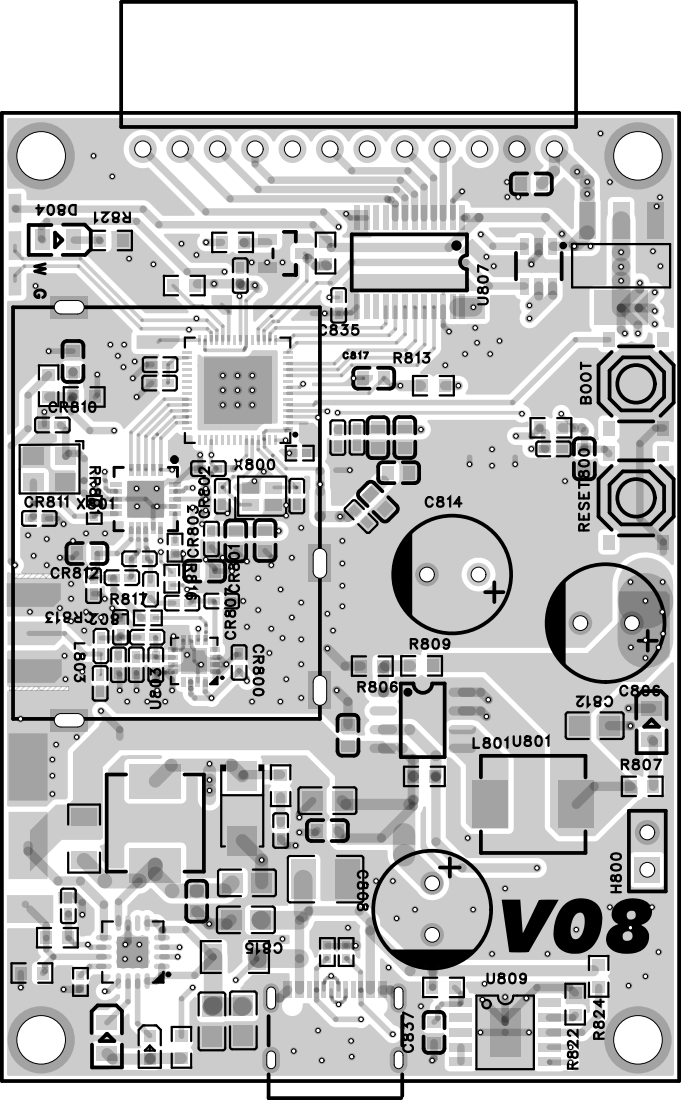
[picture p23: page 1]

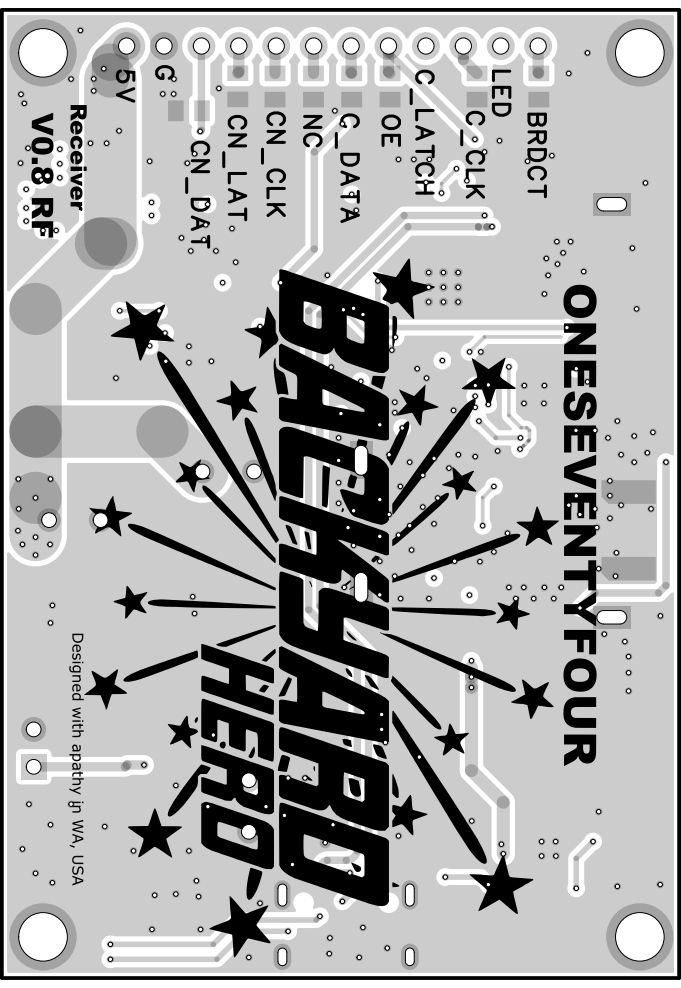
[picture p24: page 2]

Designed with apathy in WA, USA

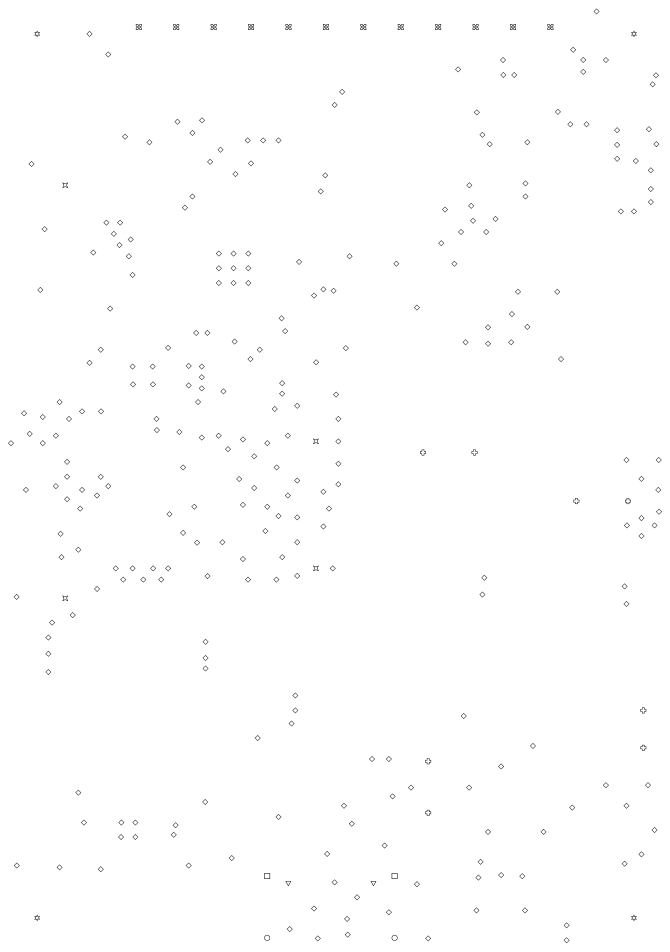
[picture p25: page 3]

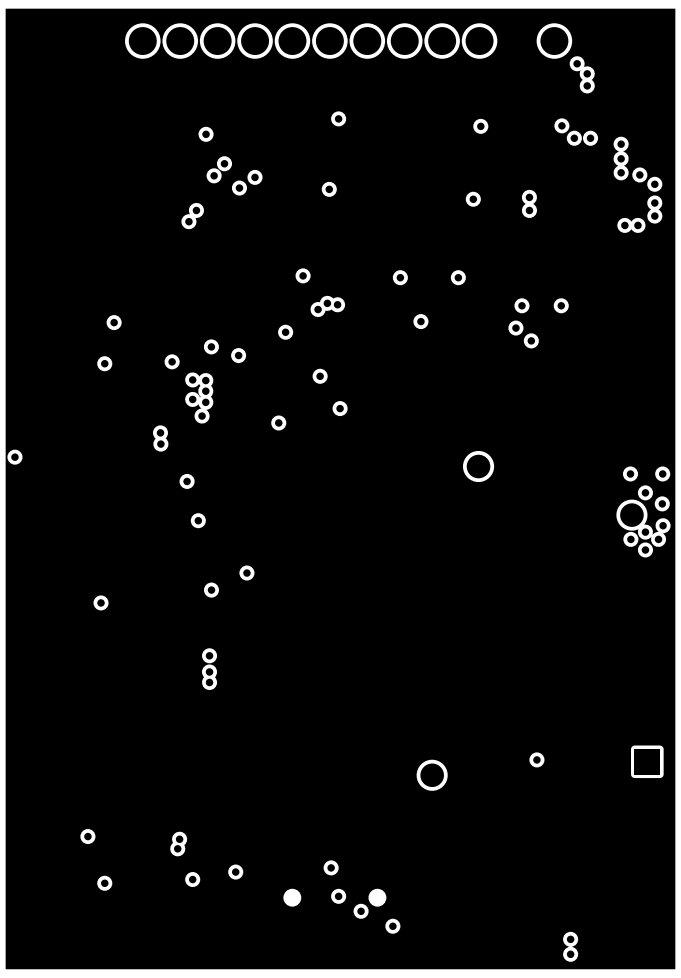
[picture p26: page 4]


## L801U⁸⁰⁷



Designed with apathy in WA, USA

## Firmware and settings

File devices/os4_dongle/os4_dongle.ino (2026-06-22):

#include <SPI.h>
#include <RF24.h>
#include <Adafruit_NeoPixel.h>
#include <ArduinoJson.h>
#include <esp_task_wdt.h>
#include <esp_system.h>   // esp_restart() for the host-requested soft reboot

// FW_VERSION: Firmware version tracking for os4_dongle
// v1: Initial version - Basic mesh networking and command queuing (date unknown)
// v2: 2025-01-XX - Added FW_VERSION tracking system with version history comments
// v3: 2025-01-XX - Migrated from RF24Mesh to pure RF24 with deterministic addressing
// v4: 2026-04-XX - ACK-payload protocol overhaul:
//   * Status piggybacks in the auto-ACK (single round trip per command)
//   * Dynamic payloads enabled (smaller frames take less air time)
//   * Non-blocking dispatcher (no inner busy-wait, no per-cmd 150ms stall)
//   * TDMA-style status polling cycle (round-robin every clockSyncIntervalMs)
//   * Soft recovery (flush_tx/rx + channel scrub instead of powerDown)
//   * Payload bounds-checking on receive
//   * MAX_RECEIVERS bumped to 32, command queue to 128
//   * Packed SHOW_LOADN (up to 6 cues per RF frame)
//   * Configurable rf_channel and rf_system_id at runtime
// v5: 2026-04-XX - Host-driven receiver registration:
//   * `forget IDENT` serial command for host-controlled removal of a
//     receiver from the poll table (host now owns the receiver list via
//     SQLite Receivers table; daemon issues `sync` / `forget` to reconcile)
// v6: 2026-05-XX - RF spectrum scan:
//   * `scan [passes [chStart chEnd]]` serial command runs an RPD-based
//     congestion sweep and emits a single `{"type":"scan_result", ...}`
//     line that the host parses and persists.
//   * Per-second status JSON now includes `ch` (current rfChannel) so the
//     UI can show the active frequency without a separate query.
// v7: 2026-05-XX - Push-on-arrival receiver telemetry:
//   * Each successful ACK-payload status update now emits a single-line
//     `{"type":"rxupd", ...}` JSON to the host the moment it arrives,
//     rather than waiting for the per-second aggregate. Status-to-host
//     latency drops from "0..1000ms (1Hz tick)" to "tens of ms" (RF retry
//     window + USB-CDC).
//   * The per-second `status` JSON is unchanged and still emitted — it
//     covers slow-changing housekeeping (queue depth, fw, channel,
//     aggregate latency) and acts as a heartbeat for the host so dropped
//     rxupd lines self-heal within a second.
// v10: 2026-05-XX - OTA flash mode (paired with receiver FW v15+):
//   * New serial commands `flash_begin / flash_data / flash_end / flash_abort`
//     drive an end-to-end firmware push from the host to a single chosen
//     receiver. While in flash mode the dongle pins itself to that one
//     receiver: regular polling and command-queue dispatch are paused,
//     and the radio data rate is hopped up to RF24_2MBPS to keep the
//     ~340KB transfer under ~30 seconds end-to-end.
//   * Each `flash_data <chunkIdx> <hex_payload>` line emits a single
//     OTA_DATA frame and reports back `ota_ack` / `ota_nack` JSON so
//     the host can pace the next chunk on success or retry on failure.
//   * After `flash_end` the dongle waits up to 30s for the receiver to
//     reboot back onto the standard 250kbps poll, then reports
//     `ota_done` (or `ota_timeout`) before resuming normal operation.
// v9: 2026-05-XX - Clamp clockSyncIntervalMs + scrub queue on `forget`:
//   * config knobs `clock_sync_interval_ms` / `response_timeout_ms` /
//     `receiver_timeout_ms` are now sanity-bounded on apply (50..30000ms,
//     5..500ms, 60s..6h respectively). Out-of-range values silently
//     broke polling -- e.g. setting csim=0 made pollSpacingMs=0 then
//     5ms-floored, which busted ACK timing on slow links. The actually-
//     applied values get echoed back in the per-second status as `csim`
//     so the host UI can show what the dongle is running with.
//   * `forget IDENT` now removes any pending queued commands targeting
//     that nodeID. Previously a forgotten receiver would still get any
//     in-flight queued commands dispatched, wasting up to ~22ms of
//     radio time per cmd on TX-FAIL retries.
// v16: 2026-05-XX - Receiver-side config query/set (paired with receiver
//   FW v22+):
//   * Two new message types:
//       RECEIVER_CONFIG_QUERY    (18) -- dongle -> receiver
//       RECEIVER_CONFIG_RESPONSE (19) -- receiver -> dongle (in ACK payload)
//   * New serial command:
//       `rxcfg IDENT`            -- pure fetch (flags=0)
//       `rxcfg IDENT fd <ms>`    -- set fire_duration_ms + fetch
//     Each command emits a single `{"type":"rxcfg", ...}` JSON line on
//     receipt of the receiver's CONFIG_RESPONSE, carrying nodeID, FW /
//     board version, NUM_BOARDS / noBoardsDetected / cuesAvailable, and
//     the actually-applied (clamped) fire_duration_ms.
//   * ACK choreography mirrors handleFlashBegin's: the dongle sends the
//     CONFIG_QUERY (its auto-ACK carries stale RECEIVER_STATUS, which
//     we ingest normally), then immediately sends a CLOCK_SYNC. The
//     receiver loaded the CONFIG_RESPONSE into its ACK FIFO between
//     those two writes, so the CLOCK_SYNC's auto-ACK carries the
//     response. Done in the same dispatchOneCommand iteration so the
//     CONFIG_RESPONSE can't get raced by another receiver's poll.
//   * Auto-query: any newly-registered receiver (autocreate via
//     getReceiverByIdent, including post-prune re-discovery) is marked
//     configQueryPending. The next poll slot for that receiver
//     dispatches a CONFIG_QUERY instead of a CLOCK_SYNC, which covers
//     the "operator turned the unit off, added a cue board, turned it
//     back on" case without UI involvement. Flag clears once the
//     CONFIG_RESPONSE is ingested.
//   * Per-receiver entries in the per-second status JSON now include
//     `fw` / `bv` / `nb` / `nbd` / `ca` / `fd` so the host can recover
//     full receiver state (e.g. post-restart) without re-querying.
// v19: V2 Board
// v18: 2026-05-XX -Command priority. 
// v17: 2026-05-XX - OTA begin handshake recovery:
//   * `flash_begin` now clears half-open OTA sessions by sending best-effort
//     OTA_ABORT probes at both 250kbps and the requested OTA rate before
//     starting a new begin. This recovers quick retries after a prior Phase A
//     success stranded the receiver at 1M/2M.
//   * If the initial 250kbps begin gets no hardware ACK, the dongle also
//     probes the requested OTA rate before failing. Error strings now
//     distinguish no begin ACK from no PREP_OK ACK.
// v15: 2026-05-XX - Non-blocking OTA serial writes + faster WDT recovery:
//   * emitOtaAck/Nack/Pong/heartbeat now build their line into a stack
//     buffer and check Serial.availableForWrite() *before* writing. If
//     the USB-CDC TX ring buffer (256B) doesn't have room, the line is
//     dropped and `otaSerialDropped` is bumped. Previously, even with
//     setTxTimeoutMs(20), Serial.print of a 30-byte line did a byte-by-
//     byte write loop where each byte could block 20ms against a backed-
//     up FIFO -- so a slow host briefly stalling drainage chained into
//     600ms+ of main-loop blocking per ack message. Drops are safe
//     because the host has its own retry/timeout layer for OTA chunks.
//   * Dropped count surfaces in the OS heartbeat (`OS att acked retries
//     last bytes phase dropped`) so the host can see backpressure.
//   * WDT timeout dropped from 20s to 10s and trigger_panic switched to
//     `false` (soft reset instead of panic). Faster recovery, USB-CDC
//     re-enumerates more reliably without a panic backtrace stalling
//     reboot.
// v14: 2026-05-XX - OTA dongle lockup recovery / link-fail mitigation:
//   * Per-second status JSON is no longer emitted during OTA. The full
//     status frame is ~400-500B; with a 256B USB-CDC TX ring buffer +
//     the per-byte setTxTimeoutMs(50) backstop, a single status print
//     while the host was slow to drain could block the main loop for
//     20+ seconds, manifesting as "dongle locked up". We now emit a
//     ~30B compact heartbeat (`OS att acked retries last\n`) instead.
//   * Every radio.write() and Serial.print() inside the OTA hot path
//     now calls yield(), which releases the CPU to FreeRTOS so the USB-
//     CDC service task can drain the TX ring buffer between operations.
//   * `flash_recover <idx> [<level>]` accepts an escalating recovery
//     level: 0 = stored-frame replay (current behavior), 1 = soft radio
//     recovery (flush FIFOs + reapply config) + replay, 2 = full
//     radio.begin() restart + reapply + 250kbps probe. Host-side
//     OtaFlashDriver now escalates 0->1->2 across host attempts 4/6/8.
//   * `flash_recover` is idempotent: if the requested chunk is already
//     <= otaLastAckedChunk it acks from cached state with no radio work.
//   * `flash_ping` liveness command emits `OP <millis> <att> <acked>\n`
//     immediately so the host can detect a wedged dongle without
//     consuming a chunk-retry slot.
//   * Hardware task watchdog (esp_task_wdt) at 20s as last-resort safety
//     net. If the OTA path ever truly wedges, the dongle resets cleanly
//     instead of staying mute.
//   * Tightened per-chunk recovery budget: OTA_PER_CHUNK_RETRIES 6->4,
//     OTA_RECOVERY_ROUNDS 4->2. Worst-case wall time per failed chunk
//     drops from ~2.1s to ~600ms, so a transient burst of interference
//     no longer chokes the serial pipe for seconds at a time -- the host
//     gets the NACK and decides whether to retry or recover.
// v20: 2026-06-XX - RF address entropy (paired with receiver FW v24+).
//   BREAKING RF change -- ship together with the matching receiver release:
//   * H8: receiverAddress() now XORs RF_ADDR_ENTROPY_MASK (0xA3C5E1B400)
//     into the computed address so the otherwise near-all-zero nRF24
//     address bytes are scattered, cutting false hardware address matches
//     and the silent packet loss they cause (worst at 250kbps). The low
//     mask byte is 0x00 so each nodeID still maps to a unique address.
//     The receiver applies the identical mask; a v20 dongle only talks to
//     a v24+ receiver. Pairs with the receiver's OTA durability work
//     (H1 CRC32 / H2.2 rollback / H3 resume) in the same release.
// v21: 2026-06-XX - Fix startload showId 1..10 parse bug:
//   * The `startload IDENT <numTargets> <showId>` parser borrowed the
//     trailing-token repeat-count heuristic used by showload/sync/fire, but
//     startload never carries a repeat suffix. A showId of 1..10 was mistaken
//     for a repeat count, which dropped the showId param and rejected the
//     command (`CV startload`). START_LOAD was never sent, so the receiver
//     kept currentShowId==0 while cues still loaded (cyan LED, showId 0).
//     Now parses exactly two params. Not an RF/protocol change -- no
//     receiver version dependency.
// v22 why not
// v25: 2026-06-XX - RESCUE release (temporary): disables the H8 RF address
//   entropy mask (RF_ADDR_ENTROPY_MASK -> 0x0) so receiverAddress() reverts to
//   the pre-v20 unmasked scheme. This lets the dongle reach PRE-v24 receivers
//   -- specifically v23 units stranded by the v20/v24 addressing break -- to
//   operate them and OTA them forward. A v25 dongle CANNOT talk to v24+
//   receivers; the follow-up release restores the mask for normal operation.
//   (Version jumps 22->25 to align with the receiver line; no v23/v24 dongle.)
// v26: 2026-06-XX - Follow-up to the v25 rescue: restores the H8 RF address
//   entropy mask (RF_ADDR_ENTROPY_MASK = 0xA3C5E1B400ULL). This is the normal
//   build -- once stranded v23 units have been OTA'd forward on the v25 rescue
//   dongle, flash v26 to resume standard masked addressing (v24+ receivers).
// v27: 2026-06-XX - RESCUE release again (identical to v25): disables the H8
//   entropy mask (-> 0x0) for another round of reaching/OTA'ing stranded
//   PRE-v24 (v23) receivers. CANNOT talk to v24+ receivers. The follow-up v28
//   restores the mask (same as v26) for normal operation.
// v28: 2026-06-XX - Follow-up to the v27 rescue (identical to v26): restores
//   the H8 RF address entropy mask (RF_ADDR_ENTROPY_MASK = 0xA3C5E1B400ULL).
//   Normal build -- flash after the v27 rescue dongle has OTA'd stranded v23
//   units forward, to resume standard masked addressing (v24+ receivers).
// v29: 2026-06-XX - Auto config re-query on reconnect:
//   * The v16 auto-query only re-fired on (re-)registration, i.e. initial
//     connect or post-prune re-discovery -- and pruning only happens after
//     receiverInactivityTimeoutMs (default 1h). A receiver that dropped and
//     came back inside that window kept its table entry, so a board/fire-
//     duration change made while it was powered off never reached the host.
//   * ingestStatusFrame now re-arms configQueryPending when a status frame
//     arrives after the receiver has been silent longer than ~4 poll cycles
//     (8s floor) -- the point at which the host already treats it as offline.
//     The next poll slot then issues a CONFIG_QUERY, same as a cold connect.
#define FW_VERSION 29

#define BOARD_VERSION 2

#define RF24_CE_PIN 37
#define RF24_CSN_PIN 36
#define RF_PIN 5

#define CONTINUITY_INDEX_CT 2
#define MAX_LATENCY_SAMPLES 10
#define MAX_SUCCESS_SAMPLES 64

#define SWITCH_START_STOP_PIN 9
#define SWITCH_ARMING_PIN 8
#define SWITCH_MAN_FIRE_PIN 7

#define LED_PIN 4
#define NUM_PIXELS 7

enum MessageType {
  MANUAL_FIRE              = 1,
  CLOCK_SYNC               = 2,
  START_LOAD               = 3,
  SHOW_LOAD                = 4,
  GENERIC_PLAY             = 5,
  GENERIC_STOP             = 6,
  GENERIC_RESET            = 7,
  GENERIC_PAUSE            = 8,
  SHOW_START               = 9,
  RECEIVER_STATUS          = 10,
  SHOW_LOADN               = 11,  // Packed multi-cue load (up to 6 cues per frame)
  RESET_DVC                = 12,
  OTA_BEGIN                = 13,
  OTA_DATA                 = 14,
  OTA_END                  = 15,
  OTA_ABORT                = 16,
  RECEIVER_OTA_STATUS      = 17,
  RECEIVER_CONFIG_QUERY    = 18,  // dongle -> receiver (paired with FW v22+)
  RECEIVER_CONFIG_RESPONSE = 19   // receiver -> dongle (in ACK payload)
};

// Bit flags for ReceiverConfigSetMessage.flags. flags == 0 is a pure
// fetch (no settings written). New writable knobs add new flag bits and
// new field slots in ReceiverConfigSetMessage; the receiver dispatch is
// msgSize-checked so older firmware just ignores trailing bytes.
#define CFG_FLAG_SET_FIRE_DURATION 0x01

struct ManualFireMessage {
  uint8_t type;
  uint8_t position;
} __attribute__((packed));

struct ClockSyncMessage {
  uint8_t type;
  uint64_t timestamp;
} __attribute__((packed));
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
void loop() {
  uint64_t now = millis() + tsOffset;

  // Feed the task watchdog. Long inner loops (OTA recovery, radio.write
  // bursts) also feed it inline -- this is the baseline tick.
  esp_task_wdt_reset();

  // Pull host commands in before routine LED/status/poll work. Manual fire
  // commands also enter the front of the queue, so the next dispatch can send
  // them ahead of background CLOCK_SYNC traffic.
  serviceSerialInput();

  checkGpioStatus();
  updateLEDs();

  // Prune inactive receivers.
  for (uint8_t i = 0; i < numReceivers; ) {
    if ((now - receivers[i].lastMessageTime) > receiverInactivityTimeoutMs) {
      Serial.print(F("INFO: Pruning inactive receiver: ")); Serial.println(receivers[i].ident);
      for (uint8_t j = i; j < numReceivers - 1; ++j) receivers[j] = receivers[j + 1];
      numReceivers--;
    } else {
      i++;
    }
  }

  // Drain any unsolicited inbound frames (e.g. from legacy receivers that
  // haven't been upgraded yet, or ACK payloads we missed).
  while (radio.available()) {
    uint8_t buf[32];
    uint8_t msgSize = radio.getDynamicPayloadSize();
    if (msgSize == 0 || msgSize > sizeof(buf)) {
      radio.flush_rx();
      break;
    }
    radio.read(&buf, msgSize);
    if (msgSize == 0) continue;
    // Unsolicited frames have no associated TX, so there's no fresh
    // latency sample to emit — pass false so the host doesn't see a
    // duplicate sample in the sliding window. ingestAckPayload also
    // emits the rxcfg JSON for CONFIG_RESPONSE arrivals here.
    ReceiverInfo* r = ingestAckPayload(buf, msgSize, now);
    if (r && buf[0] == RECEIVER_STATUS) emitRxUpd(r, false);
  }

  // While OTA flash mode is active, the dongle is pinned to one receiver
  // and the radio is on a non-standard data rate. Skip the regular
  // polling and command-dispatch paths -- otherwise we'd write to other
  // receivers at the wrong rate (no ACK, retries waste air time) and
  // try to consume queued commands for receivers we promised the
  // operator we'd ignore until the flash completes.
  if (otaActive) {
    serviceOtaRejoin(now);
  } else {
    // TDMA-style status polling — spreads one CLOCK_SYNC per slot across the
    // configured interval so all known receivers get updated regularly without
    // bursting.
    maybePollNextReceiver(now);

    // One queued command per loop iteration. radio.write() blocks at most
    // ~22ms on a failed write (5 retries × ~3.75ms ARD), and ~3ms on success.
    // No busy-poll, no inner timeout loop.
    if (!isQueueEmpty()) dispatchOneCommand(now);
  }

  // Per-second status JSON for the host.
  //
  // FW v14: while OTA is active, skip the full status JSON entirely.
  // The status frame is ~400-500 bytes (one receiver entry + housekeeping)
  // and the dongle's USB-CDC TX ring buffer is only 256 bytes. With the
  // setTxTimeoutMs(20) backstop, a single full status print while the
  // host is briefly slow to drain (docker log buffering, daemon mid-state-
  // write, etc.) can block the main loop for hundreds of ms; chained with
  // the OTA hot-path retry burst that's how a "transient RF burst" turned
  // into a multi-second silent dongle. Emit a 30-byte compact heartbeat
  // instead -- enough for the host to show progress / detect liveness.
  //   `OS <attempted> <acked> <retries> <last> <bytes_acked>\n`
  if (now - lastPrintTime >= 1000) {
    lastPrintTime = now;
    if (otaActive) {
      // FW v15: non-blocking heartbeat. Includes otaSerialDropped so
      // the host can spot persistent backpressure (drops mean the host
      // is not draining serial fast enough -- usually a docker log
      // driver issue or a daemon mid-state-write).
      //   OS <attempted> <acked> <retries> <last> <bytes> <phase> <dropped>
      char buf[80];
      int n = snprintf(buf, sizeof(buf), "OS %u %u %u %u %lu %u %lu\n",
                       (unsigned)otaChunksAttempted,
                       (unsigned)otaChunksAcked,
                       (unsigned)otaHwRetryBursts,
                       (unsigned)otaLastAckedChunk,
                       (unsigned long)((uint32_t)otaChunksAcked *
                                       (uint32_t)OTA_MAX_CHUNK_BYTES),
                       (unsigned)otaPhase,
                       (unsigned long)otaSerialDropped);
      if (n > 0 && n < (int)sizeof(buf)) {
        otaEmitLineNonBlocking(buf, (size_t)n);
      }
    } else {
      DynamicJsonDocument doc(1024 + (numReceivers * 256));
      doc["timestamp"] = now;
      doc["q"] = cmdQueueCount;
      // Expose queue capacity so the UI can render q/qmax as a saturation
      // bar without hardcoding the dongle constant on the host side.
      // Cheap (one extra int per second).
      doc["qmax"] = MAX_COMMANDS_IN_QUEUE;
      doc["fw"] = FW_VERSION;
      doc["ch"] = rfChannel;
      // Echo the live (post-clamp) clock-sync interval so the UI can show
      // the operator what the dongle is actually running with -- e.g. if
      // they typed 0 in settings, they'll see CSIM_MIN_MS reflected here
      // rather than wondering why polling didn't change.
      doc["csim"] = clockSyncIntervalMs;

      uint32_t totalLat = 0; int avgLat = 0;
      if (latencySampleCount > 0) {
        for (uint8_t i = 0; i < latencySampleCount; i++) totalLat += latencies[i];
        avgLat = round((float)totalLat / latencySampleCount);
      }
      doc["l"] = avgLat;

      JsonArray arr = doc.createNestedArray("receivers");
      for (uint8_t i = 0; i < numReceivers; i++) {
        JsonObject ro = arr.createNestedObject();
        ro["i"] = receivers[i].ident;
        ro["n"] = receivers[i].nodeID;
        ro["b"] = receivers[i].batteryLevel;
        ro["s"] = receivers[i].showId;
        ro["l"] = receivers[i].loadComplete ? 1 : 0;
        ro["r"] = receivers[i].startReady   ? 1 : 0;
        ro["t"] = receivers[i].lastMessageTime;

        uint32_t rsum = 0; int rAvg = 0;
        if (receivers[i].latencySampleCount > 0) {
          for (uint8_t k = 0; k < receivers[i].latencySampleCount; k++) rsum += receivers[i].latencies[k];
          rAvg = round((float)rsum / receivers[i].latencySampleCount);
        }
        ro["x"] = rAvg;
        ro["sp"] = calculateSuccessPercent(&receivers[i]);

        // FW v16: include the cached receiver-side config when valid.
        // Skipped entirely on receivers we haven't queried yet so the
        // host can tell "no answer yet" from "really has 0 cues".
        if (receivers[i].configValid) {
          ro["fw"]  = receivers[i].fwVersion;
          ro["bv"]  = receivers[i].boardVersion;
          ro["nb"]  = receivers[i].numBoards;
          ro["nbd"] = receivers[i].noBoardsDetected;
          ro["ca"]  = receivers[i].cuesAvailable;
          ro["fd"]  = receivers[i].fireDurationMs;
        }

        JsonArray ca = ro.createNestedArray("c");
        for (uint8_t j = 0; j < CONTINUITY_INDEX_CT; j++) ca.add(receivers[i].continuity[j]);
      }
      String out;
      serializeJson(doc, out);
      Serial.println(out);
    }
  }

  // Service any bytes that arrived while we were doing RF/status work.
  serviceSerialInput();
}

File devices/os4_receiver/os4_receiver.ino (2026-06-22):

#include <SPI.h>
#include <RF24.h>
#include <Adafruit_NeoPixel.h>
#include <Preferences.h>
#include <Update.h>
#include "esp_ota_ops.h"   // H2.2: boot self-test / rollback confirmation

// FW_VERSION: Firmware version tracking for os4_receiver
// v1-v4: Historical versions (not documented, dates unknown)
// v5: Baseline version before tracking system (date unknown)
// v6: 2025-01-XX - Added FW_VERSION tracking system with version history comments
// v7: 2025-01-XX - Migrated from RF24Mesh to pure RF24 with deterministic addressing
// v8: previous baseline
// v9: 2026-04-XX - ACK-payload protocol overhaul (matches dongle FW v4):
//   * Status piggybacks in the auto-ACK FIFO (no separate sendStatus TX path)
//   * Dynamic payloads enabled
//   * Payload bounds-checked on receive
//   * ADDITIONAL_CLOCK_TX_OFFSET now applied to clock_offset
//   * Hot-path Serial prints gated behind DEBUG_PRINT
//   * Show-time LED animations are now non-blocking state machines so radio
//     servicing isn't stalled during them
//   * Configurable rf_channel and rf_system_id (compile-time, matches dongle)
//   * SHOW_LOADN handler (packed multi-cue load)
// v10: 2026-05-XX - Fix RF address aliasing. RECEIVER_BASE is now
//   arithmetically *added* to NODE_ID instead of OR'd. Pre-v10 receivers
//   with even NODE_IDs already used `BASE+N` by accident (because OR
//   with 0x01 == +1 when LSB=0), so they don't move; receivers with odd
//   NODE_IDs shift up by one address slot. Pair only with dongle FW v8+.
// v11: 2026-05-XX - Adaptive disconnect detection + ACK-payload freshness:
//   * Disconnect threshold now scales with the observed inter-poll gap
//     (median of the last 8 successful contacts, * 5x, floored at 5s and
//     capped at 60s). The dongle's clockSyncIntervalMs * numReceivers
//     can range from ~50ms to many seconds; the old fixed 10s timeout
//     false-fired the moment the operator slowed polling for a large
//     fleet. Now a fleet polled every 8s tolerates a missed ACK without
//     declaring "disconnect" until ~40s of true silence.
//   * refreshAckPayload() now flushes the ACK TX FIFO before writing
//     so the dongle never receives a stale (>250ms) status piggyback
//     when commands come in faster than the periodic refresh.
// v12: 2026-05-XX - Don't abort the show on radio dropout + clock-domain fix:
//   * The disconnect detection used `now = millis() + clock_offset` for
//     `lastCmdReceived` but recomputed `now` with the LATEST clock_offset
//     on the following loop iteration. A CLOCK_SYNC inside the same iter
//     would mutate clock_offset, so the next iteration's
//     `now - lastCmdReceived` included the entire clock-offset delta --
//     enough to trip the 5s floor on any meaningful clock jump (e.g. an
//     msync at daemon restart, or jitter compounding over minutes), even
//     though no real time had elapsed. That manifested as a quick
//     magenta `ANIM_FLASHING_PURPLE` flash mid-show and the receiver
//     halting all subsequent cue fires. Now we track `lastCmdReceived`
//     in raw `millis()` so the disconnect math is monotonic and
//     unaffected by clock_offset updates.
//   * Even on a real disconnect, we no longer clear `isPlaying`. The
//     show is loaded locally with absolute synchronized fire times --
//     a brief RF dropout doesn't invalidate any of that, and aborting
//     the autonomous schedule is exactly the wrong response. The radio
//     is still re-armed and we still flash purple so the operator sees
//     the blip, but cues continue to fire on the loaded schedule. The
//     operator can hit STOP if they want a hard abort.
// v13: 2026-05-XX - Relax receiver disconnect tolerance:
//   * Minimum disconnect threshold increased from 5s to 8s.
//   * Adaptive threshold increased from 5x to 6x observed poll gap.
//   * Maximum threshold increased from 60s to 90s.
// v15: 2026-05-XX - OTA flash mode (paired with dongle FW v10+):
//   * New message types OTA_BEGIN(13) / OTA_DATA(14) / OTA_END(15) /
//     OTA_ABORT(16) and a piggy-back ACK status RECEIVER_OTA_STATUS(17).
//   * On OTA_BEGIN we call Update.begin(totalSize), switch the radio to
//     the high data rate the dongle requested (1Mbps or 2Mbps), and
//     start streaming chunks straight into the OTA partition via
//     Update.write(). Each chunk is up to 29 bytes (32B nRF payload -
//     1B type - 2B chunkIdx); the dongle's auto-retry handles loss.
//   * On OTA_END we Update.end(true), accept-the-image, and ESP.restart()
//     -- the bootloader picks the new partition next boot. NVS is
//     untouched so identity (NODE_ID + RECEIVER_IDENT) survives.
//   * On OTA_ABORT or any local error, Update.abort() runs and the
//     radio switches back to the standard 250kbps so the receiver can
//     resume normal polling without a reboot.
//   * While the OTA state machine is active, runPlayLoop / animation /
//     status-LED updates are suspended; the status strip shows a slow
//     dim-white breathe so the operator can see the unit is being
//     reflashed. We keep refreshing the ACK payload on every chunk so
//     the dongle gets up-to-date `bytesReceived` / `lastChunk` /
//     `state` / `errorCode` for progress reporting up to the host.
// v16: 2026-05-XX - Boot-time status-LED sequence now encodes FW_VERSION
//   and NODE_ID as 3-digit decimal numbers across the 3 status LEDs:
//   * The boot sequence is now three flashes:
//       1. FW_VERSION (digit-color, breath in/out)
//       2. Battery level (existing behavior, unchanged: bar count + color)
//       3. NODE_ID     (digit-color, breath in/out)
//     The 1st and 3rd used to be a single fixed-purple breath and a
//     fixed-white fade respectively, neither of which carried any per-
//     unit information. That made it impossible to tell at a glance
//     which firmware or which receiver had just powered up -- a real
//     problem during incremental rollouts and during fleet bring-up.
//   * For both the version and node-id flashes, each status LED shows
//     one decimal digit:
//       LED 0 = hundreds digit
//       LED 1 = tens digit
//       LED 2 = ones digit
//     For example FW v20 -> LED0 red(0), LED1 yellow(2), LED2 red(0);
//     FW v16 -> LED0 red(0), LED1 red(0), LED2 orange(6). NODE_ID 137
//     -> LED0 blue(1), LED1 green(3), LED2 white(7).
//   * Each digit 0..9 maps to a fixed, vivid color chosen so consecutive
//     digits are maximally distinct (so 1 vs 2 or 7 vs 8 are obvious at
//     a glance, even if 2 vs 5 could be confused at a distance):
//       0 red    1 blue   2 yellow 3 green  4 purple
//       5 cyan   6 orange 7 white  8 pink   9 lime
//     The LEDs all breathe in/out together at the same brightness curve
//     the old purple breath used, so the boot "feel" is unchanged --
//     just informative.
//   * Only the boot flashes change. The unprovisioned magenta breath, the
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

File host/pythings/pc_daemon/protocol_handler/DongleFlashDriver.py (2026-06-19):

"""Dongle flash driver -- the daemon's view of a UI-driven dongle update.

Where the receiver-OTA flow streams chunks over RF (driven by
OtaFlashDriver in this same package), the dongle update is fundamentally
different: the dongle's USB-CDC port is owned by the host-side
tcp_serial_bridge, so this driver doesn't drive esptool itself. Instead
it talks HTTP to the bridge's /flash_dongle endpoint:

    daemon                           bridge (host loopback :9001)
    ─────                           ─────────────────────────────
    POST /flash_dongle  ───────────▶  pause forwarders, fork esptool
                       ◀───────────   {accepted: true, job_id}
    GET  /flash_dongle/status         (worker thread runs esptool,
                       (poll loop)     parses Writing-at-pct lines)
                       ◀───────────   {phase, overall_pct, ...}
    POST /flash_dongle/continue       (operator-confirmed BOOT+RESET,
                                       worker rretries with no_reset)
    POST /flash_dongle/abort          (kill esptool subprocess)

The bridge's /flash_dongle/status is the source of truth for live
state; this driver's job is to (a) gate-check on the daemon's side
(no flash while a show is loaded or armed), (b) translate UI commands
into HTTP calls, and (c) republish the status into fw_state.dongle_ota
so the existing WebSocket fan-out delivers updates to the browser
without a separate polling channel.
"""

from __future__ import annotations

import base64
import json
import os
import threading
import time
from typing import Optional
from urllib import error as urlerror
from urllib import request as urlrequest


# Where to find the host-side bridge's flasher endpoint. host.docker.internal
# resolves to the host loopback inside docker (Docker Desktop on Mac/Win does
# this natively; on Linux we wire it up via extra_hosts in compose). On a
# native install (no docker) the same env override lets the daemon point
# at 127.0.0.1.
FLASH_HTTP_HOST = os.environ.get("BYH_FLASH_HOST", "host.docker.internal")
FLASH_HTTP_PORT = int(os.environ.get("BYH_FLASH_PORT", "9001"))
FLASH_BASE_URL = f"http://{FLASH_HTTP_HOST}:{FLASH_HTTP_PORT}"

# Default poll cadence. esptool's progress output ticks at roughly 5-10Hz
# during the write phase; 5Hz is plenty for a smooth UI bar without
# burning CPU on a Pi.
POLL_INTERVAL_S = 0.2

# How long we let a single HTTP request hang before giving up. The bridge
# normally responds in <50ms; anything beyond a couple seconds means the
# bridge process is wedged.
HTTP_TIMEOUT_S = 4.0

# Dongle-update timeline guard. From "submit job" to "phase=done|error|
# aborted" must complete within this many seconds, otherwise we declare
# the bridge wedged and surface an error in the UI. The longest legitimate
# run is full-flash mode at ~30s + manual-reset prompt at up to 5min,
# so 7 minutes leaves comfortable headroom.
JOB_LIFETIME_LIMIT_S = 7 * 60.0
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

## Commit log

2025-12-29 Toasty errors and receiver cloning
    [os4_receiver.ino]
2026-02-15 V9 Receptor de radio y corrección de errores
    [os4_receiver.ino]
2026-02-24 7 led dongle and refresh catalog from OS4 web
2026-05-09 OTA v1
    [partitions.csv]
2026-05-16 Dongle OTA fixes and mobile fix
    [os4_dongle.ino]
2026-06-18 Add desktop package-lock.json so CI npm ci works
    The build-desktop workflow installs deps with `npm ci`, which requires a
    committed lockfile. host/desktop/ never had one, so every leg (macOS
    arm64/x64, Windows) failed at the install step. Generated and validated
    with `npm ci --dry-run`.
2026-06-18 Fix desktop CI build: Windows .cmd spawn + empty signing env
    Two failures surfaced once npm ci worked:
    * build-resources.mjs spawned npm.cmd/npx.cmd with shell:false; Node
    refuses to exec .cmd shims without a shell (CVE-2024-27980), so the
    Windows "Assemble resources" step died with status=null. Spawn .cmd
    shims through a shell on Windows.
    * The workflow injected empty CSC_LINK/WIN_CSC_LINK when the signing
    secrets are unset. electron-builder treats "" as a cert path, resolves
    it to the project dir, and fails with "host/desktop not a file" on both
    macOS and Windows. Only export signing/notarization vars when the secret
    is present; otherwise build a clean unsigned artifact.
    C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
2026-06-18 Pin Windows desktop build to windows-2022
    windows-latest now runs Windows 2025 with Visual Studio v18, which the
    node-gyp 10.1.0 bundled with Node 20 can't detect (it errors with
    ERR_CHILD_PROCESS_STDIO_MAXBUFFER, then "could not find Visual Studio
    2017 or newer"), failing the better-sqlite3 native build. VS 2022 on
    windows-2022 is detected correctly.
2026-06-18 Move desktop Intel mac build to macos-15-intel
    macos-13 was retired on 2025-12-04, so the macOS x64 leg queued forever
    with no runner assigned. macos-15-intel is GitHub's replacement x86_64
    image (last Intel runner, supported until ~Aug 2027).
2026-06-18 Drop macOS x64 (Intel) desktop build leg
    The remaining GitHub Intel image (macos-15-intel) has no prebuilt
    llvmlite/numba wheel for the embedded x86_64 Python, so the librosa audio
    stack tries to compile llvmlite from source and fails at the cmake/LLVM
    step (no toolchain on the runner). Apple Silicon (macos-14) covers modern
    Macs and Intel runners retire ~Aug 2027 regardless.
2026-06-19 Dongle OTA fix on electron
    [flash_server.py, tcp_serial_bridge.py]
2026-06-19 ci: create BINDIR before installing arduino-cli in release-firmware
    The arduino-cli install.sh now aborts with "$BINDIR folder not found" if the
    target dir doesn't already exist, breaking the firmware build/publish. mkdir -p
    the dir first.
2026-06-22 Confirm fix, logo fix
    [os4_dongle.ino, os4_receiver.ino, pc_daemon.py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]
2026-06-22 Conn lifecycle fixes for dongle
    [pc_daemon.py, tcp_serial_bridge.py]
2026-06-23 Fix builder timeline issues
    [pc_daemon.py]
2026-06-25 BHWB-18/17 fix + file a ticket
    [BYHProtocolHandler.py, pc_daemon.py, tcp_serial_bridge.py]
2026-07-01 Duration fix and editor ease of use stuff
    [BYHProtocolHandler.py, pc_daemon.py]
2026-07-02 Show editor/timeline overhaul, host-device audio playback, and a hardware-free dev container
2026-07-02 Add COBRA + Finale3D show import with inventory/catalog matching
    Import sources:
    - COBRA Script CSV converter (channel->receiver, cue->target; seeds show
    name from #Script Name).
    - Finale3D native .fin converter: unzips the archive client-side via
    DecompressionStream (deflate-raw, no new deps) and reads show_tables.txt;
    rail/pin -> receiver/cue, partNumber -> label.
    Item matching:
    - New "Match items" wizard step auto-links each cue name to inventory
    (normalized, case/whitespace-tolerant); matched cues import as real
    inventory-backed items (itemId set), unmatched stay generic.
    - Combined master-detail "Match imported items" window: cue list + inline
    resolver and full catalog sear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
2026-07-02 Fix H1: preserve operator-entered cue delay across inventory edits
    Editing an inventory item re-hydrates its placed cues and recomputes
    `delay = metaDelaySec + item fuse/lift`. `metaDelaySec` was not in
    SAVEABLE_ITEM_ATTRIBUTES, so cues from previously saved shows had
    `metaDelaySec === undefined` and the recompute silently collapsed the
    persisted delay to just the fuse/lift, changing actual firing timing.
    - Persist `metaDelaySec` (SAVEABLE_ITEM_ATTRIBUTES + NUMERIC coercion).
    - For legacy cues that predate it, back the extra delay out of the cue's
    current total using the item's pre-edit fuse/lift so firing time is
    preserved, not collapsed.
    - Mirror the same guarded re-sync in refreshInv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
2026-07-02 Fix H3: don't block GENERIC cues when inventory is empty
    openAddModal called requireInventory(), so an empty inventory hard-blocked
    every add entry point (double-click, right-click "Add here") even though the
    Add modal supports GENERIC cues (name + typed duration) that need no
    inventory item. Drop the gate here; the inventory-item flows keep their own
    requireInventory gate.
2026-07-02 Fix M7: don't toggle show audio via Space behind an open modal
    The Space handler only exempted INPUT/TEXTAREA/SELECT/BUTTON/contentEditable,
    so with the Add/Edit modal (or inline inventory form) open and focus on the
    dialog body, Space started/stopped the show preview behind the modal. Bail
    when a [role="dialog"] is present, matching the Ctrl/Cmd+S guard.
2026-07-02 Fix H2/M1/M2/M3/L4: host audio reconnect resilience, per-track anchoring
    These four changes rework one interdependent path (the manifest format goes
    from urls[] to tracks[] with per-track durations), so they land together:
    - H2: a transient WS hiccup no longer tears down in-flight playback. main()
    leaves the local player subprocess running on reconnect, and the state loop
    re-arms idempotently (or stops if the show actually ended). A restarted
    process now arm()s with the live sst and seeks in (-ss) instead of playing
    from 0:00.
    - M1: re-anchor each track to base + sum(prior durations) so per-track
    spawn/decode latency stops accumulating against the firing clock; late
    tracks seek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
2026-07-02 Fix M5: correct devcontainer hardware docs (mock vs real bridge)
    The README said the in-container daemon reaches a real dongle via the
    host-side bridge, but supervisord.devcontainer.conf points it at the
    in-container mock, which reports a healthy dongle and silently swallows fire
    commands. Rewrite the hardware section with the mock-by-default reality and
    an explicit "using real hardware" procedure (stop mock-bridge, re-point
    BYH_BRIDGE_HOST, restart the daemon). Fix mock_bridge.py's docstring, which
    claimed it's wired into supervisord.dev.conf (it's the devcontainer conf).
    [mock_bridge.py]
2026-07-02 Fix M6: discrete controls no longer commit an unsaved latency edit
    onToggle/onDevice persisted the whole draft, sneaking a deviceLatencyMs the
    operator typed but hadn't confirmed via the SaveBar into the saved config.
    Commit those discrete changes against the last-saved latency and keep the
    in-progress trim edit in the draft (still dirty).
2026-07-02 devcontainer: share node_modules/.next with the workspace path
    The app source is bind-mounted a second time at the VS Code workspace path,
    but node_modules lived only in the named volume overlaid on /app/byh_app, so
    tooling run from the workspace copy (next lint/build, eslint, package scripts)
    couldn't find deps. Mount the same named volumes at the workspace path too.
2026-07-02 Host audio settings: add a "Test" tone button per output device
    Add a Test button next to the output-device dropdown that plays a short
    lavfi-generated tone out of the selected device so the operator can confirm
    it makes sound before a live show. The new /api/system/audio_test route
    mirrors the audio_player daemon's playback path (ffplay for the system
    default, ffmpeg's alsa muxer for a specific device) and reports device-open
    failures by stderr marker since ffplay exits 0 even when it can't open the
    output. Hardware-guarded and local-only. Switching devices clears the prior
    result.
2026-07-02 Host audio: list connected Bluetooth (bluez-alsa) sinks as outputs
    aplay -L only exposes a generic bluealsa PCM, so paired A2DP speakers/headsets
    were never selectable. Enumerate them with bluealsa-aplay -L (per-device id +
    name) and append to /api/system/audio_devices. Best-effort: absent when
    bluez-alsa isn't installed or nothing is connected.
2026-07-02 Timeline: marquee multi-select, group context menu, click-empty clears
    Drag across empty timeline background to rubber-band select every unlocked
    cue it intersects; the set becomes the multi-selection on release. Right-
    clicking a cue that's part of a 2+ selection opens a group menu (chain
    timing, lock, clear, delete N). Clicking empty background now reliably
    clears the selection by testing for a data-cue ancestor rather than an
    exact target/stale class match.
2026-07-03 Show builder: undo/redo history, first-run setup, movable video preview
    Add a visual undo/redo history for the timeline plus several editor UX
    changes:
    - Undo/redo history: linear, append-only log of item snapshots with a
    History panel (step list + diff inspector), per-show sessionStorage
    persistence, and Ctrl/Cmd+Z / Y / Shift+Z + Ctrl/Cmd+A shortcuts.
    Jumping back and then editing records a "Reverted to ..." step so the
    branch point is visible in the log.
    - First-run setup screen: a new/unsaved show must be named + given an arm
    code and saved before receivers or cues can be added.
    - Video preview popup is now a draggable floating window (persisted
    position); auto-open on selec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
2026-07-03 Show Details: arm code field with reveal + edit
    Add the show's arm code to the Show Details tab, masked by default with a
    click-to-reveal toggle and an edit button. Edits write to showMetadata so the
    builder's existing auto-save (its fingerprint already includes
    authorization_code) persists the change.
2026-08-17 Support board NVS record, higher IDS
2026-11-14 Omni board status comms, performance fixes
